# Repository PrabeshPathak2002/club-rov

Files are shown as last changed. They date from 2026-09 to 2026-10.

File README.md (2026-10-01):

# Club ROV — learning and underwater sensor testing

Project repository: [PrabeshPathak2002/club-rov](https://github.com/PrabeshPathak2002/club-rov).

A six-thruster, tethered remotely operated vehicle for club operations, testing sensors for a RoboSub AUV, training new members, and outreach. The intended operating depth is **20–50 m**, a design target that still requires physical qualification.

## Explore the ROV in 3D

<table>
<tr>
<td width="78%">
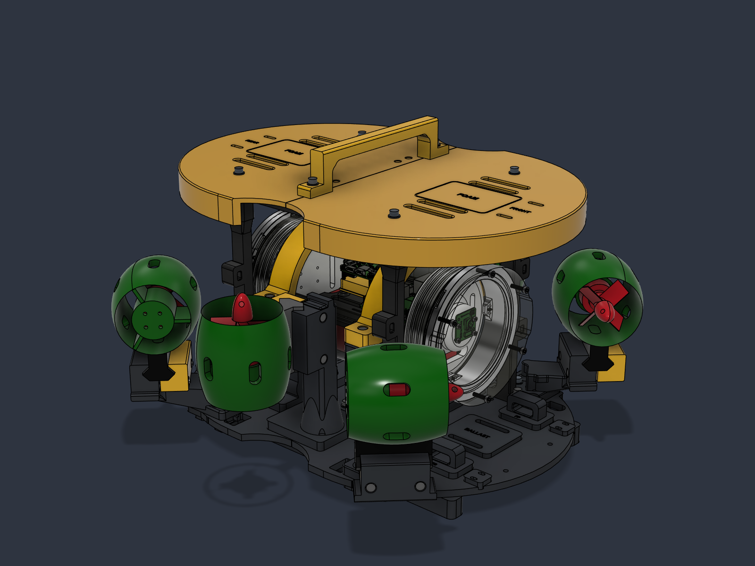
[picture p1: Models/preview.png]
Club ROV assembly in yellow and graphite — click to view in 3D

</td>
<td align="center" valign="middle">

<br><br>
Rotate, pan, and zoom the detailed model.
</td>
</tr>
</table>

[Model scope and attribution](Models/README.md). The assembly STL is for viewing, not printing.

## Purpose

- Evaluate candidate AUV sensors before integrating them into the autonomous vehicle.
- Teach CAD, additive manufacturing, electronics, embedded software, controls, and experimental testing.
- Demonstrate the club's work for promotion and recruitment, while documenting the engineering process as a portfolio project.

## Status

Latest mechanical revision: [M4 side-frame joints](Final%20Design/README.md#m4-frame-joints), standardizing the 38 custom frame/mount screws to M4. The [rear horizontal thruster pair remains corrected](Final%20Design/README.md#orientation-and-checks); the front horizontal and vertical pairs retain their orientations. The image and 3D model show this revision.

The current mechanical design and print exports are prepared. Physical assembly, electrical integration, companion firmware, and water qualification remain ahead. Existing geometry checks do not establish a depth or structural load rating.

The design uses a modular PETG frame, an existing 4-inch, 200 mm enclosure, and six APISQUEEN U01 thrusters. An ARK FPV running ArduSub is planned for vehicle control; a Waveshare ESP32-P4-WIFI6-POE-ETH will handle camera and Ethernet communications with a USB MAVLink connection to the ARK. Propulsion uses a planned 4S 4000 mAh pack, a DakeFPV four-channel ESC, and two additional ESCs. PoE and a proposed backup battery support the companion electronics. Sensors and several electrical details remain undecided.

## Start here

- [New member learning path](Documentation/NEW_MEMBERS.md)
- [System architecture and open decisions](Documentation/ARCHITECTURE.md)
- [Testing plan](Documentation/TESTING.md) and [test report template](Documentation/templates/TEST_REPORT.md)
- [Roadmap](Documentation/ROADMAP.md)
- [Contributing](CONTRIBUTING.md)
- [Attribution and publishing scope](Documentation/PUBLISHING.md)

## Local design package

GitHub contains documentation and lightweight assembly viewing models. Binary design assets and historical files below remain local pending a distribution and attribution review; their download links will not resolve in this GitHub copy.

- **[Final Design](Final%20Design/README.md)** — current Fusion assembly, STEP, printable files, BOM, assembly guide, validation and previews. Start here.
- **[Archive](Archive/Design%20History%202026-09-29/README.md)** — preserved design history, scripts, logs and earlier revisions.
- **3D models/** — original component/reference downloads, retained in place.
- **Code/** — existing firmware/software files, retained in place.
- **Documentation/** — other project documentation and the organization script.

The earlier structure/S6Hybrid development folder has moved into Archive. Existing chat links to that older location may no longer resolve; use Final Design for the current deliverables. The cleanup preserved all 1,588 original design-history files and verified their SHA-256 hashes after the move.

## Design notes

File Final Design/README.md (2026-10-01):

# Final ROV design

Current revision: M4 side-frame joints, 30 September 2026. Start with the assembly and printing guide below.

Current orientation revision: rear horizontal pair flipped back; front horizontal and vertical pairs retain their reversed orientations. The current relieved receiver pockets and print files are unchanged by this correction. See [revision details and fit-test requirements](#orientation-and-checks). Earlier validation reports are historical where superseded by the rear-pair correction reports.

- [Complete Fusion assembly](CAD/S6_Hybrid_Service_Upgrade.f3d)
- [Print-oriented Fusion parts](CAD/Service_Upgrade_Print_Parts.f3d)
- [Frame STEP export](CAD/Service_Upgrade_Frame.step) — frame component only, not the complete enclosure/thruster assembly
- [Print package](Prints/Service_Upgrade_STLs.zip) — 27 assembly parts, 10 fit coupons, guides, BOM, checks and adapter references
- [Individual STL files](Prints/Service_Upgrade_STLs/)
- [BOM spreadsheet CSV](BOM/Current_ROV_BOM.csv) and [BOM notes](BOM/Current_ROV_BOM.md)
- [Printing and assembly guide](Guides/PRINT_GUIDE.md)
- [Validation reports](Validation/) and [design previews](Previews/)
- [Future thruster adapter references](Thruster%20Interface%20References/README.md)

Current hardware: 38 M4 custom frame/mount screws, 34 nuts, 56 washers and four M4 inserts. The reused enclosure/electronics CAD also contains 30 screw solids. The BOM explains exclusions and unspecified accessories.

## M4 frame joints

The four side-frame screws are now M4x30, with four M4 heat-set inserts (6 mm maximum OD x 8.1 mm length) and 9x4.4x0.8 mm washers. The beam holes are 4.5 mm; insert pilots are 5.6 mm diameter and 10.2 mm deep. Four uprights and two beams must be printed from the new M4 files. Test all three M4 joint coupons with the actual inserts before full printing. All 38 custom screws now use M4 threads; the imported enclosure hardware remains separately specified.

The conversion passed 71 candidate intersection checks with only the four intentional insert/pilot overlaps, plus 402 sampled service checks. All 37 STLs passed watertightness, winding, scale and solid-volume checks. Thruster transforms were retained and Fusion reported no timeline issues. These checks do not establish joint strength or a lifting rating.

## Orientation and checks

The rear port and rear starboard horizontal thrusters are flipped back to their original orientation. The front horizontal and vertical pairs retain their reversed orientations, giving four vectored horizontal and two vertical units. The current relieved receiver pockets still fit; this correction does not change printed parts or fastener quantities.

The rear-pair correction passed six candidate intersection checks and all 402 sampled service-clearance checks, with no Fusion timeline warnings or errors. The other four thruster transforms were verified unchanged. These are nominal CAD checks; physical rail fit, cable routing, motor mapping, and actual thrust directions still need testing.

This is the current design release, not a physically qualified vehicle. Lifting/attachment loads, final electronics, tether, buoyancy and ballast still require the checks described in the guide. Ten test coupons are not installed parts. The six adapter references are not complete working mounts.

Earlier revisions, experiments, scripts, raw tool logs and backups are preserved at ../Archive/Design History 2026-09-29/S6Hybrid/. No original design-history files were deleted. The archive inventory and restore instructions are in that archive's parent folder. Original source models, code and other project documents remain in their original project folders.

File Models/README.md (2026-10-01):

# Interactive assembly preview

Current revision: [M4 side-frame joints](../Final%20Design/README.md#m4-frame-joints), with the [rear horizontal pair corrected](../Final%20Design/README.md#orientation-and-checks); the front horizontal and vertical pairs retain their orientations. The relieved fixed-receiver pockets are retained.

[Open the detailed STL in GitHub's 3D viewer](club-rov-preview.stl). Drag to rotate, right-drag to pan, and scroll to zoom.

The root README displays a full-color Fusion screenshot beside a View in 3D button. Both open the detailed binary STL in GitHub's interactive viewer. The STL includes the enclosure flanges and stays below GitHub's 10 MB viewer limit. STL is monochrome; the screenshot shows the design colors.

Exported from the active Future ROV Fusion assembly on 30 September 2026. Includes the enclosure, six thrusters, frame, clamps, and handle. Internal electronics, liners, and fasteners are omitted. This mesh is not a printable assembly or a manufacturing reference; use the original individual print parts for fabrication.

The assembly includes imported enclosure and APISQUEEN U01 reference geometry alongside the custom frame and mounts. No new ownership or reuse license is asserted over third-party designs. See [publishing and attribution](../Documentation/PUBLISHING.md).

[GitHub's STL documentation](https://docs.github.com/en/get-started/writing-on-github/working-with-advanced-formatting/creating-diagrams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)

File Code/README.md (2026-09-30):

# Companion firmware workspace

Firmware is not implemented yet. This folder contains local ESP-IDF setup configuration, not a runnable ROV application.

The planned target is the Waveshare ESP32-P4-WIFI6-POE-ETH. It will handle Ethernet, the camera, and USB-host MAVLink communication with the ARK FPV running ArduSub. The ARK owns thruster control.

Implementation awaits remaining software requirements and hardware decisions. See the [architecture](../Documentation/ARCHITECTURE.md) and [roadmap](../Documentation/ROADMAP.md).

When firmware is added, record the board revision, ESP-IDF version, dependencies, build/flash/monitor commands, settings, expected startup output, and bench-test procedure. Do not publish credentials or local machine paths. Initial ignore rules admit only this README from this folder; extend them deliberately when code is ready.

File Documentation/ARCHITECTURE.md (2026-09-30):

# System architecture

Status: planned electrical architecture, recorded 29 September 2026. This is an explanation of responsibilities, not a validated wiring guide.

## Control and data

The intended command path is topside operator → Ethernet tether → ESP32-P4 → USB MAVLink → ARK FPV running ArduSub → six ESC channels → thrusters. Telemetry returns in the opposite direction. Camera data is intended to reach the surface through the ESP32 and Ethernet.

The ARK owns motor control and vehicle failsafes. The ESP32 is a companion responsible for communications and camera handling. Its USB host driver and MAVLink bridge are not implemented. Camera interface, driver, stream format, and achievable latency remain to be established.

The project owner has used the ARK with ArduSub in previous submarines; this vehicle still requires integration testing. Depth, sonar, and other sensors are deliberately undecided. For each sensor, record its power, interface, calibration, timestamps, logging format, and whether the ARK or companion will own it.

## Mechanical platform

Six APISQUEEN U01 thrusters use four horizontal and two vertical mounts. The PETG frame retains the existing 4-inch, 200 mm enclosure. Printing is planned on an H2D with 100% infill as the requested starting point. Print orientation, joints, sealing, and loads still need physical validation. The 20–50 m operating depth remains a target.

## Power

- A 4S 4000 mAh battery is planned for propulsion and the ARK battery input through the ESC harness.
- DakeFPV lists the GT 6S 55A with 3–6S input and VBAT output. ARK lists a 5.5–54 V VBAT input. These ranges support the proposed feed; cable pin order is unverified.
- Two additional ESCs supply channels five and six; exact models are TBD.
- PoE powers the companion and accessories. Backup battery chemistry, capacity, charging, power-path circuitry, and switchover behavior remain TBD.
- Simultaneous ARK VBAT and USB power behavior needs verification. Backup power cannot restore a severed Ethernet link.

## Open decisions and checks

1. ESC connector wiring and reversible thrust operation; bidirectional DShot wording alone does not confirm reverse thrust.
2. USB enumeration, power interaction, MAVLink routing, and reconnect behavior.
3. Camera compatibility and video/control latency under load.
4. Power consumption, PoE budget, battery endurance, and thermal behavior.
5. Tether, penetrators, sealing, buoyancy, ballast, and depth qualification.
6. Topside software, operator controls, and explicit ArduSub link-loss behavior.

## Primary references

- [DakeFPV GT 6S 55A](https://www.dakefpv.com/pd.jsp?id=97)
- [ARK FPV pinout](https://docs.arkelectron.com/products/flight-controller/ark-fpv/pinout)
- [Waveshare ESP32-P4-WIFI6-POE-ETH](https://docs.waveshare.com/ESP32-P4-WIFI6-POE-ETH)
- [Espressif USB CDC host](https://components.espressif.com/components/espressif/usb_host_cdc_acm)

Match documentation to the actual hardware revision before preparing wiring instructions.

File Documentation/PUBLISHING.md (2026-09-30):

# Publishing and attribution

GitHub includes project, training, architecture, testing, roadmap, BOM, and printing documentation, plus a detailed assembly viewing model and one design screenshot in `Models/`. The README shows the screenshot beside a View in 3D button linking to the model. This is not a backup of the full local CAD project.

## Local-only assets

The archive holds over 5 GB of development history. Imported reference models, raw logs, machine-specific configuration, CAD, STL files, ZIP packages, and previews remain local. The full Fusion assembly is approximately 110 MB. Choose a reviewed release-asset or large-file distribution method before publishing it.

Some design-document links point to local assets and will not resolve in the initial GitHub copy. Replace them with release links once reviewed downloads are published. Preserve the archive separately.

## Attribution

The layout is inspired by the Hydrocean S6 reference provided during design. The vehicle reuses an enclosure and imported commercial-component CAD. Do not imply affiliation or equivalent performance.

Record the club name, contributors and roles, source of the enclosure and each imported model, redistribution terms, and permissions for product imagery. Credit ArduSub/ArduPilot, Espressif, ARK, Waveshare, DakeFPV, and APISQUEEN where their work or hardware is used. Links to electrical references are in [ARCHITECTURE.md](ARCHITECTURE.md).

No project-wide license has been selected. Public visibility does not grant a reuse license. A future license for original code, documentation, or custom mechanics must not claim ownership of third-party assets.

For the portfolio, explain the engineering problem, your specific contributions, tradeoffs, and measured results. Credit collaborators and tools accurately; CAD checks are not physical test results.

## Publication checklist

- [x] Confirm GitHub owner, repository name, and visibility: public, [PrabeshPathak2002/club-rov](https://github.com/PrabeshPathak2002/club-rov).
- [x] Review tracked files for credentials, local paths, and unrelated content.
- [x] Create and push the repository; record its URL in the README.
- [ ] Complete attribution and select licenses with the relevant owners.
- [ ] Publish reviewed design downloads and replace local-only links.
- [ ] Add selected project photos and measured test results.

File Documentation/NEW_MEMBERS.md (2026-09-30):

# New member learning path

Begin with an unpowered vehicle or its design files and work with a project mentor. Prior underwater robotics experience is not required.

## 1. Understand the vehicle

Read the project README and [architecture](ARCHITECTURE.md). Identify the enclosure, six thrusters, flight controller, companion, tether, and power sources. Explain how a command reaches a motor and how video returns to the surface.

Deliverable: an annotated sketch and questions for your mentor.

## 2. Practice mechanical work

Read the [print guide](../Final%20Design/Guides/PRINT_GUIDE.md) and [BOM](../Final%20Design/BOM/Current_ROV_BOM.md). Start with a fit coupon. Record material, orientation, slicer settings, and measured fit. Practice heat-set inserts on a spare coupon with supervision.

Deliverable: a fit report with dimensions and photos. Fit alone does not establish strength or pressure capability. Binary print files currently belong to the complete local design package.

## 3. Trace the electronics

Use actual board documentation to identify connector orientation, polarity, signal ground, VBAT, and regulated supplies. The architecture overview is not a pin-by-pin wiring guide. Keep propulsion disabled during initial communications work.

Deliverable: a reviewed wiring sketch with exact revisions and unresolved connections marked.

## 4. Learn the software

Read [Code/README.md](../Code/README.md). Once firmware exists, reproduce a build before changing behavior. Learn what a MAVLink heartbeat means and why video alone does not prove a healthy control link.

Deliverable: a reproducible build or documentation improvement. Until firmware is available, diagram normal operation, USB reconnection, and tether loss.

## 5. Participate in supervised testing

Follow the [testing plan](TESTING.md). Agree on acceptance criteria, abort conditions, and operator/observer/recovery responsibilities before starting. Powered propulsion and water trials require the club's designated supervisor.

Deliverable: a completed [test report](templates/TEST_REPORT.md), including unexpected results and follow-up actions.

## 6. Contribute and teach

Take a small change through a pull request using [CONTRIBUTING.md](../CONTRIBUTING.md). Explain it to another member. At demonstrations, distinguish tested capabilities from planned ones.

## Common terms

- ROV: remotely operated vehicle, controlled from the surface.
- AUV: autonomous underwater vehicle.
- ESC: electronic speed controller for a motor.
- Companion: the ESP32 communications/camera board in this project.
- MAVLink: the planned flight-controller messaging protocol.
- PoE: power over Ethernet through compatible equipment.
- BOM: bill of materials.

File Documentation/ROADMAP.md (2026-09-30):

# Roadmap

## Prepared

- [x] Define club operations, AUV sensor evaluation, training, and outreach purposes.
- [x] Prepare the mechanical design, print exports, BOM, and assembly guidance.
- [x] Select companion and flight-controller responsibilities.
- [x] Draft documentation and newcomer learning path.

## Integration preparation

- [ ] Confirm camera, additional ESCs, hardware revisions, tether, and backup power.
- [ ] Verify ESC wiring/reverse operation and simultaneous USB/VBAT behavior after parts arrive.
- [ ] Define topside controls, video requirements, and failure behavior.
- [ ] Complete electrical BOM and reviewed wiring diagram.
- [ ] Confirm repository visibility and asset attribution/distribution terms.

## Companion software

- [ ] Establish a reproducible ESP-IDF build and board identification procedure.
- [ ] Bring up Ethernet and diagnostics.
- [ ] Implement USB CDC/MAVLink routing and reconnection.
- [ ] Integrate the confirmed camera and measure latency under load.
- [ ] Add logging and supported power-status reporting.
- [ ] Document setup, configuration, troubleshooting, and bench tests.

## Qualification and club use

- [ ] Validate print fit, assembly, and mechanical loading.
- [ ] Complete bench integration and failure tests.
- [ ] Qualify sealing and shallow-water operation.
- [ ] Establish demonstrated depth and endurance.
- [ ] Add sensor evaluation procedures and datasets.
- [ ] Record a demonstration and portfolio case study with measured results.

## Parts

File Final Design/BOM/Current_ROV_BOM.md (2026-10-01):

# Current ROV bill of materials

Revision: M4 side-frame joints, 30 September 2026. This is a design BOM based on the active Future ROV document and its current print exports, not a fully validated purchasing list. Model labels do not prove ownership or final electrical compatibility. Prices are not estimated.

27 printed assembly parts; six U01 thrusters. The 10 supplied fit coupons and six STEP interface references are not installed vehicle parts. PETG spool quantity must come from the slicer, including supports, brim, coupons and waste.

Custom frame/mount hardware: 38 screws, 34 nuts, 56 washers and four inserts. Separately, 30 screw solids belong to the reused enclosure/electronics assembly. Thus 68 screw solids are accounted for across those two scopes; this does not include unitemized factory thruster hardware or future accessories.

Electrical gap: one four-channel ESC is represented for six thrusters. Two additional suitable channels or a revised ESC arrangement remain unspecified. The modeled battery is labeled 4S 4000 mAh; the reference S6 vendor battery specification was not substituted.

## Printed assembly

- **1 part** — Lower collar and foot -1. PETG; 100% infill requested. Lower_collar_and_foot_-1.stl
- **1 part** — Removable upper collar -1. PETG; 100% infill requested. Removable_upper_collar_-1.stl
- **1 part** — Lower collar and foot 1. PETG; 100% infill requested. Lower_collar_and_foot_1.stl
- **1 part** — Removable upper collar 1. PETG; 100% infill requested. Removable_upper_collar_1.stl
- **1 part** — H Rear Starboard fixed receiver and support. PETG; 100% infill requested. H_Rear_Starboard_fixed_receiver_and_support.stl
- **1 part** — H Rear Port fixed receiver and support. PETG; 100% infill requested. H_Rear_Port_fixed_receiver_and_support.stl
- **1 part** — H Front Starboard fixed receiver and support. PETG; 100% infill requested. H_Front_Starboard_fixed_receiver_and_support.stl
- **1 part** — H Front Port fixed receiver and support. PETG; 100% infill requested. H_Front_Port_fixed_receiver_and_support.stl
- **1 part** — V Starboard fixed receiver and support. PETG; 100% infill requested. V_Starboard_fixed_receiver_and_support.stl
- **1 part** — V Port fixed receiver and support. PETG; 100% infill requested. V_Port_fixed_receiver_and_support.stl
- **1 part** — H Rear Starboard removable rail jaw. PETG; 100% infill requested. H_Rear_Starboard_removable_rail_jaw.stl
- **1 part** — H Rear Port removable rail jaw. PETG; 100% infill requested. H_Rear_Port_removable_rail_jaw.stl
- **1 part** — H Front Starboard removable rail jaw. PETG; 100% infill requested. H_Front_Starboard_removable_rail_jaw.stl
- **1 part** — V Starboard removable rail jaw. PETG; 100% infill requested. V_Starboard_removable_rail_jaw.stl
- **1 part** — H Front Port removable rail jaw. PETG; 100% infill requested. H_Front_Port_removable_rail_jaw.stl
- **1 part** — V Port removable rail jaw. PETG; 100% infill requested. V_Port_removable_rail_jaw.stl
- **1 part** — Rear lower deck half - H2D. PETG; 100% infill requested. Rear_lower_deck_half_-_H2D.stl
- **1 part** — Rear upper cover half - H2D. PETG; 100% infill requested. Rear_upper_cover_half_-_H2D.stl
- **1 part** — Front lower deck half - H2D. PETG; 100% infill requested. Front_lower_deck_half_-_H2D.stl
- **1 part** — Front upper cover half - H2D. PETG; 100% infill requested. Front_upper_cover_half_-_H2D.stl
- **1 part** — One-piece service handle - two bolts. PETG; 100% infill requested. One-piece_service_handle_-_two_bolts.stl
- **1 part** — Starboard rear upright - M4 insert. PETG; 100% infill requested. Starboard_rear_upright_-_M4_insert.stl
- **1 part** — Starboard front upright - M4 insert. PETG; 100% infill requested. Starboard_front_upright_-_M4_insert.stl
- **1 part** — Starboard top beam - keyed M4 joints. PETG; 100% infill requested. Starboard_top_beam_-_keyed_M4_joints.stl
- **1 part** — Port rear upright - M4 insert. PETG; 100% infill requested. Port_rear_upright_-_M4_insert.stl
- **1 part** — Port front upright - M4 insert. PETG; 100% infill requested. Port_front_upright_-_M4_insert.stl
- **1 part** — Port top beam - keyed M4 joints. PETG; 100% infill requested. Port_top_beam_-_keyed_M4_joints.stl

## Custom assembly hardware

- **16 screw** — M4 x 20 socket-head screw. Dimensions in mm; screw length excludes head. Material/grade to be selected.
- **4 screw** — M4 x 25 socket-head screw. Dimensions in mm; screw length excludes head. Material/grade to be selected.
- **2 screw** — M4 x 35 socket-head screw. Dimensions in mm; screw length excludes head. Material/grade to be selected.
- **12 screw** — M4 x 45 socket-head screw. Dimensions in mm; screw length excludes head. Material/grade to be selected.
- **4 screw** — M4 x 30 socket-head screw. Dimensions in mm; screw length excludes head. Material/grade to be selected.
- **34 nut** — M4 hex nut. Nominal 7 mm across flats x 3.2 mm thick; retained pockets are not sized for arbitrary locknuts.
- **16 washer** — M4 washer: 8 mm OD / 4.4 mm ID / 0.8 mm thick. Collar and rail-clamp washers; radii checked in active Fusion document.
- **40 washer** — M4 washer: 9 mm OD / 4.4 mm ID / 0.8 mm thick. Frame and mounting washers; radii checked in active Fusion document.
- **4 insert** — M4 heat-set insert: 6.0 mm maximum OD x 8.1 mm long. 5.6 mm nominal pilot, 10.2 mm deep. Test actual insert in coupon before full printing.

## Existing enclosure/electronics hardware

- **6 screw** — 90037A105 screw (imported CAD label). Counted separate screw solids. Thread/length and purchased item not independently verified; do not order solely from this label.
- **4 screw** — 91290A006 screw (imported CAD label). Counted separate screw solids. Thread/length and purchased item not independently verified; do not order solely from this label.
- **4 screw** — 91290A011 screw (imported CAD label). Counted separate screw solids. Thread/length and purchased item not independently verified; do not order solely from this label.
- **4 screw** — 91290A124 screw (imported CAD label). Counted separate screw solids. Thread/length and purchased item not independently verified; do not order solely from this label.
- **6 screw** — 91292A114 screw (imported CAD label). Counted separate screw solids. Thread/length and purchased item not independently verified; do not order solely from this label.
- **6 screw** — 91292A115 screw (imported CAD label). Counted separate screw solids. Thread/length and purchased item not independently verified; do not order solely from this label.

## Existing enclosure and internals

- **1 piece / assembly** — 4-inch acrylic enclosure tube, 200 mm long. Existing enclosure; measured tube OD 114.3 mm.
- **2 piece / assembly** — 4-inch O-ring flange assembly. Each imported flange assembly contains two CAD bodies. Seal quantities and kit contents require confirmation.
- **1 piece / assembly** — Front acrylic end cap. Existing Acrylic_end_cap_blank component.
- **1 piece / assembly** — Rear aluminum end cap, five M10 openings. Existing Aluminum_end_cap_5XM10 CAD label. Actual penetrator choices remain unspecified.
- **2 piece / assembly** — Internal mounting rail BR-102784-200 RevA. Reused CAD components.
- **1 piece / assembly** — Electronics tray. Existing tray; excluded from the 27 newly supplied printed frame/mount parts.

## Enclosure mounting

- **4 half** — 1 mm soft enclosure liner half. Two upper and two lower halves, one pair per collar. Not a rigid PETG print.

## Propulsion

- **4 assembly** — APISQUEEN U01 thruster with attached rail — horizontal. Includes supplied thruster/rail geometry; factory hardware is not separately itemized.
- **2 assembly** — APISQUEEN U01 thruster with attached rail — vertical. Includes supplied thruster/rail geometry; factory hardware is not separately itemized.

## Existing electronics

- **1 assembly** — Turnigy 4S 4000 mAh battery. From Battery_Turnigy_4S_4000 CAD label; actual pack and operating limits need confirmation.
- **1 assembly** — 4-in-1 55 A ESC board. From ESC_4in1_55A CAD label. Four channels represented; reversible operation and compatibility not verified.
- **1 assembly** — ARK FPV Rev 1.0 board. One board, regardless of its 887 imported CAD bodies. Role and wiring are not validated here.
- **1 assembly** — ESP32-P4-WIFI6-POE-ETH board. One board, regardless of its 821 imported CAD bodies. Power and communication implementation remains to be finalized.
- **1 assembly** — Cam V2.1 camera module. One imported camera assembly; exact electrical interface/variant to confirm.

## Unspecified / not procurement-ready

- **2 channel** — Additional thruster ESC channels. Six motors need six suitable channels; only a four-channel board is represented. Two extra channels or a replacement six-channel arrangement must be specified.
- **TBD length** — Tether cable. Diameter, length, construction and communication/power arrangement not chosen.
- **1 assembly** — Tether strain-relief assembly. Select for actual tether; use lower-frame eye through suitable soft loop/strap. Load rating unassigned.
- **TBD piece** — Cable ties / cable retention straps. Twelve printed cable-tie locations: eight upright guides and four deck tie pairs. Final routing determines quantity and size.
- **TBD set** — Buoyancy material and retaining straps. Two upper mounting areas; material, depth rating, volume and strap quantity to be selected after weight/trim assessment.
- **TBD set** — Ballast and its retention hardware. Two slotted lower mounting pads; mass and hardware depend on measured buoyancy and trim.
- **TBD assembly** — Lifting/recovery bridle or spreader arrangement. Optional future rigging for four lower-frame eyes. Routing, working load and physical tests not established.
- **TBD set** — Enclosure O-rings / seals. Confirm exact flange kit and seal sizes/quantities; not separately identifiable in the snapshot.
- **TBD set** — Cable penetrators / blanking plugs / connectors. Rear cap has five M10 openings in the CAD label; allocation and sealing hardware not finalized.
- **TBD set** — Power wiring, distribution, fuse and isolation hardware. Electrical architecture and current requirements not validated.
- **TBD set** — Topside communication/control equipment. Tether communication interface and operator controls to be specified.
- **TBD set** — Battery charger and operating spares. Support equipment; select after actual battery and electrical design are confirmed.

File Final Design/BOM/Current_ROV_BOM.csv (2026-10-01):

category | item | quantity | unit | status | notes | source
Printed assembly | Lower collar and foot -1 | 1 | part | Modeled / STL supplied | PETG; 100% infill requested. Lower_collar_and_foot_-1.stl | Current Fusion service-upgrade revision
Printed assembly | Removable upper collar -1 | 1 | part | Modeled / STL supplied | PETG; 100% infill requested. Removable_upper_collar_-1.stl | Current Fusion service-upgrade revision
Printed assembly | Lower collar and foot 1 | 1 | part | Modeled / STL supplied | PETG; 100% infill requested. Lower_collar_and_foot_1.stl | Current Fusion service-upgrade revision
Printed assembly | Removable upper collar 1 | 1 | part | Modeled / STL supplied | PETG; 100% infill requested. Removable_upper_collar_1.stl | Current Fusion service-upgrade revision
Printed assembly | H Rear Starboard fixed receiver and support | 1 | part | Modeled / STL supplied | PETG; 100% infill requested. H_Rear_Starboard_fixed_receiver_and_support.stl | Current Fusion service-upgrade revision
Printed assembly | H Rear Port fixed receiver and support | 1 | part | Modeled / STL supplied | PETG; 100% infill requested. H_Rear_Port_fixed_receiver_and_support.stl | Current Fusion service-upgrade revision
Printed assembly | H Front Starboard fixed receiver and support | 1 | part | Modeled / STL supplied | PETG; 100% infill requested. H_Front_Starboard_fixed_receiver_and_support.stl | Current Fusion service-upgrade revision
Printed assembly | H Front Port fixed receiver and support | 1 | part | Modeled / STL supplied | PETG; 100% infill requested. H_Front_Port_fixed_receiver_and_support.stl | Current Fusion service-upgrade revision
Printed assembly | V Starboard fixed receiver and support | 1 | part | Modeled / STL supplied | PETG; 100% infill requested. V_Starboard_fixed_receiver_and_support.stl | Current Fusion service-upgrade revision
Printed assembly | V Port fixed receiver and support | 1 | part | Modeled / STL supplied | PETG; 100% infill requested. V_Port_fixed_receiver_and_support.stl | Current Fusion service-upgrade revision
Printed assembly | H Rear Starboard removable rail jaw | 1 | part | Modeled / STL supplied | PETG; 100% infill requested. H_Rear_Starboard_removable_rail_jaw.stl | Current Fusion service-upgrade revision
Printed assembly | H Rear Port removable rail jaw | 1 | part | Modeled / STL supplied | PETG; 100% infill requested. H_Rear_Port_removable_rail_jaw.stl | Current Fusion service-upgrade revision
Printed assembly | H Front Starboard removable rail jaw | 1 | part | Modeled / STL supplied | PETG; 100% infill requested. H_Front_Starboard_removable_rail_jaw.stl | Current Fusion service-upgrade revision
Printed assembly | V Starboard removable rail jaw | 1 | part | Modeled / STL supplied | PETG; 100% infill requested. V_Starboard_removable_rail_jaw.stl | Current Fusion service-upgrade revision
Printed assembly | H Front Port removable rail jaw | 1 | part | Modeled / STL supplied | PETG; 100% infill requested. H_Front_Port_removable_rail_jaw.stl | Current Fusion service-upgrade revision
Printed assembly | V Port removable rail jaw | 1 | part | Modeled / STL supplied | PETG; 100% infill requested. V_Port_removable_rail_jaw.stl | Current Fusion service-upgrade revision
Printed assembly | Rear lower deck half - H2D | 1 | part | Modeled / STL supplied | PETG; 100% infill requested. Rear_lower_deck_half_-_H2D.stl | Current Fusion service-upgrade revision
Printed assembly | Rear upper cover half - H2D | 1 | part | Modeled / STL supplied | PETG; 100% infill requested. Rear_upper_cover_half_-_H2D.stl | Current Fusion service-upgrade revision
Printed assembly | Front lower deck half - H2D | 1 | part | Modeled / STL supplied | PETG; 100% infill requested. Front_lower_deck_half_-_H2D.stl | Current Fusion service-upgrade revision
Printed assembly | Front upper cover half - H2D | 1 | part | Modeled / STL supplied | PETG; 100% infill requested. Front_upper_cover_half_-_H2D.stl | Current Fusion service-upgrade revision
Printed assembly | One-piece service handle - two bolts | 1 | part | Modeled / STL supplied | PETG; 100% infill requested. One-piece_service_handle_-_two_bolts.stl | Current Fusion service-upgrade revision
Printed assembly | Starboard rear upright - M4 insert | 1 | part | Modeled / STL supplied | PETG; 100% infill requested. Starboard_rear_upright_-_M4_insert.stl | Current Fusion service-upgrade revision
Printed assembly | Starboard front upright - M4 insert | 1 | part | Modeled / STL supplied | PETG; 100% infill requested. Starboard_front_upright_-_M4_insert.stl | Current Fusion service-upgrade revision
Printed assembly | Starboard top beam - keyed M4 joints | 1 | part | Modeled / STL supplied | PETG; 100% infill requested. Starboard_top_beam_-_keyed_M4_joints.stl | Current Fusion service-upgrade revision
Printed assembly | Port rear upright - M4 insert | 1 | part | Modeled / STL supplied | PETG; 100% infill requested. Port_rear_upright_-_M4_insert.stl | Current Fusion service-upgrade revision
Printed assembly | Port front upright - M4 insert | 1 | part | Modeled / STL supplied | PETG; 100% infill requested. Port_front_upright_-_M4_insert.stl | Current Fusion service-upgrade revision
Printed assembly | Port top beam - keyed M4 joints | 1 | part | Modeled / STL supplied | PETG; 100% infill requested. Port_top_beam_-_keyed_M4_joints.stl | Current Fusion service-upgrade revision
Custom assembly hardware | M4 x 20 socket-head screw | 16 | screw | Modeled | Dimensions in mm; screw length excludes head. Material/grade to be selected. | Current Fusion service-upgrade revision
Custom assembly hardware | M4 x 25 socket-head screw | 4 | screw | Modeled | Dimensions in mm; screw length excludes head. Material/grade to be selected. | Current Fusion service-upgrade revision
Custom assembly hardware | M4 x 35 socket-head screw | 2 | screw | Modeled | Dimensions in mm; screw length excludes head. Material/grade to be selected. | Current Fusion service-upgrade revision
Custom assembly hardware | M4 x 45 socket-head screw | 12 | screw | Modeled | Dimensions in mm; screw length excludes head. Material/grade to be selected. | Current Fusion service-upgrade revision
Custom assembly hardware | M4 x 30 socket-head screw | 4 | screw | Modeled | Dimensions in mm; screw length excludes head. Material/grade to be selected. | Current Fusion service-upgrade revision
Custom assembly hardware | M4 hex nut | 34 | nut | Modeled | Nominal 7 mm across flats x 3.2 mm thick; retained pockets are not sized for arbitrary locknuts. | Current Fusion service-upgrade revision
Custom assembly hardware | M4 washer: 8 mm OD / 4.4 mm ID / 0.8 mm thick | 16 | washer | Modeled | Collar and rail-clamp washers; radii checked in active Fusion document. | Current Fusion service-upgrade revision
Custom assembly hardware | M4 washer: 9 mm OD / 4.4 mm ID / 0.8 mm thick | 40 | washer | Modeled | Frame and mounting washers; radii checked in active Fusion document. | Current Fusion service-upgrade revision
Custom assembly hardware | M4 heat-set insert: 6.0 mm maximum OD x 8.1 mm long | 4 | insert | Design basis; exact product unconfirmed | 5.6 mm nominal pilot; 10.2 mm deep. Test actual insert in coupon before full printing. | Current Fusion service-upgrade revision
Existing enclosure/electronics hardware | 90037A105 screw (imported CAD label) | 6 | screw | Modeled in reused assembly | Counted separate screw solids. Thread/length and purchased item not independently verified; do not order solely from this label. | Original enclosure snapshot in active Fusion document
Existing enclosure/electronics hardware | 91290A006 screw (imported CAD label) | 4 | screw | Modeled in reused assembly | Counted separate screw solids. Thread/length and purchased item not independently verified; do not order solely from this label. | Original enclosure snapshot in active Fusion document
Existing enclosure/electronics hardware | 91290A011 screw (imported CAD label) | 4 | screw | Modeled in reused assembly | Counted separate screw solids. Thread/length and purchased item not independently verified; do not order solely from this label. | Original enclosure snapshot in active Fusion document
Existing enclosure/electronics hardware | 91290A124 screw (imported CAD label) | 4 | screw | Modeled in reused assembly | Counted separate screw solids. Thread/length and purchased item not independently verified; do not order solely from this label. | Original enclosure snapshot in active Fusion document
Existing enclosure/electronics hardware | 91292A114 screw (imported CAD label) | 6 | screw | Modeled in reused assembly | Counted separate screw solids. Thread/length and purchased item not independently verified; do not order solely from this label. | Original enclosure snapshot in active Fusion document
Existing enclosure/electronics hardware | 91292A115 screw (imported CAD label) | 6 | screw | Modeled in reused assembly | Counted separate screw solids. Thread/length and purchased item not independently verified; do not order solely from this label. | Original enclosure snapshot in active Fusion document
Existing enclosure and internals | 4-inch acrylic enclosure tube, 200 mm long | 1 | piece / assembly | Modeled; reuse intended | Existing enclosure; measured tube OD 114.3 mm. | Current Fusion service-upgrade revision
Existing enclosure and internals | 4-inch O-ring flange assembly | 2 | piece / assembly | Modeled; reuse intended | Each imported flange assembly contains two CAD bodies. Seal quantities and kit contents require confirmation. | Current Fusion service-upgrade revision
Existing enclosure and internals | Front acrylic end cap | 1 | piece / assembly | Modeled; reuse intended | Existing Acrylic_end_cap_blank component. | Current Fusion service-upgrade revision
Existing enclosure and internals | Rear aluminum end cap, five M10 openings | 1 | piece / assembly | Modeled; reuse intended | Existing Aluminum_end_cap_5XM10 CAD label. Actual penetrator choices remain unspecified. | Current Fusion service-upgrade revision
Existing enclosure and internals | Internal mounting rail BR-102784-200 RevA | 2 | piece / assembly | Modeled; reuse intended | Reused CAD components. | Current Fusion service-upgrade revision
Existing enclosure and internals | Electronics tray | 1 | piece / assembly | Modeled; reuse intended | Existing tray; excluded from the 27 newly supplied printed frame/mount parts. | Current Fusion service-upgrade revision
Enclosure mounting | 1 mm soft enclosure liner half | 4 | half | Modeled; material to select | Two upper and two lower halves, one pair per collar. Not a rigid PETG print. | Current Fusion service-upgrade revision
Propulsion | APISQUEEN U01 thruster with attached rail — horizontal | 4 | assembly | Modeled | Includes supplied thruster/rail geometry; factory hardware is not separately itemized. | Current Fusion service-upgrade revision
Propulsion | APISQUEEN U01 thruster with attached rail — vertical | 2 | assembly | Modeled | Includes supplied thruster/rail geometry; factory hardware is not separately itemized. | Current Fusion service-upgrade revision
Existing electronics | Turnigy 4S 4000 mAh battery | 1 | assembly | Present in CAD; configuration unverified | From Battery_Turnigy_4S_4000 CAD label; actual pack and operating limits need confirmation. | Current Fusion service-upgrade revision
Existing electronics | 4-in-1 55 A ESC board | 1 | assembly | Present in CAD; configuration unverified | From ESC_4in1_55A CAD label. Four channels represented; reversible operation and compatibility not verified. | Current Fusion service-upgrade revision
Existing electronics | ARK FPV Rev 1.0 board | 1 | assembly | Present in CAD; configuration unverified | One board, regardless of its 887 imported CAD bodies. Role and wiring are not validated here. | Current Fusion service-upgrade revision
Existing electronics | ESP32-P4-WIFI6-POE-ETH board | 1 | assembly | Present in CAD; configuration unverified | One board, regardless of its 821 imported CAD bodies. Power and communication implementation remains to be finalized. | Current Fusion service-upgrade revision
Existing electronics | Cam V2.1 camera module | 1 | assembly | Present in CAD; configuration unverified | One imported camera assembly; exact electrical interface/variant to confirm. | Current Fusion service-upgrade revision
Unspecified / not procurement-ready | Additional thruster ESC channels | 2 | channel | Required or optional provision; see notes | Six motors need six suitable channels; only a four-channel board is represented. Two extra channels or a replacement six-channel arrangement must be specified. | Current Fusion service-upgrade revision
Unspecified / not procurement-ready | Tether cable | TBD | length | Required or optional provision; see notes | Diameter, length, construction and communication/power arrangement not chosen. | Current Fusion service-upgrade revision
Unspecified / not procurement-ready | Tether strain-relief assembly | 1 | assembly | Required or optional provision; see notes | Select for actual tether; use lower-frame eye through suitable soft loop/strap. Load rating unassigned. | Current Fusion service-upgrade revision
Unspecified / not procurement-ready | Cable ties / cable retention straps | TBD | piece | Required or optional provision; see notes | Twelve printed cable-tie locations: eight upright guides and four deck tie pairs. Final routing determines quantity and size. | Current Fusion service-upgrade revision
Unspecified / not procurement-ready | Buoyancy material and retaining straps | TBD | set | Required or optional provision; see notes | Two upper mounting areas; material, depth rating, volume and strap quantity to be selected after weight/trim assessment. | Current Fusion service-upgrade revision
Unspecified / not procurement-ready | Ballast and its retention hardware | TBD | set | Required or optional provision; see notes | Two slotted lower mounting pads; mass and hardware depend on measured buoyancy and trim. | Current Fusion service-upgrade revision
Unspecified / not procurement-ready | Lifting/recovery bridle or spreader arrangement | TBD | assembly | Required or optional provision; see notes | Optional future rigging for four lower-frame eyes. Routing, working load and physical tests not established. | Current Fusion service-upgrade revision
Unspecified / not procurement-ready | Enclosure O-rings / seals | TBD | set | Required or optional provision; see notes | Confirm exact flange kit and seal sizes/quantities; not separately identifiable in the snapshot. | Current Fusion service-upgrade revision
Unspecified / not procurement-ready | Cable penetrators / blanking plugs / connectors | TBD | set | Required or optional provision; see notes | Rear cap has five M10 openings in the CAD label; allocation and sealing hardware not finalized. | Current Fusion service-upgrade revision
Unspecified / not procurement-ready | Power wiring, distribution, fuse and isolation hardware | TBD | set | Required or optional provision; see notes | Electrical architecture and current requirements not validated. | Current Fusion service-upgrade revision
Unspecified / not procurement-ready | Topside communication/control equipment | TBD | set | Required or optional provision; see notes | Tether communication interface and operator controls to be specified. | Current Fusion service-upgrade revision
Unspecified / not procurement-ready | Battery charger and operating spares | TBD | set | Required or optional provision; see notes | Support equipment; select after actual battery and electrical design are confirmed. | Current Fusion service-upgrade revision

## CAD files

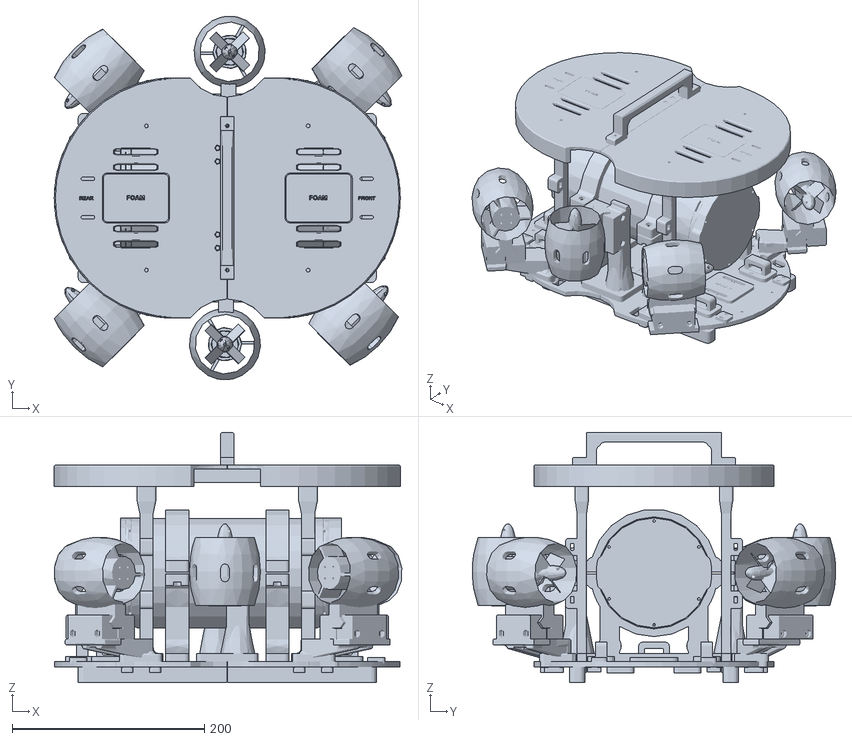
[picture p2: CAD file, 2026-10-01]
Models/club-rov-preview.stl
361.5 x 377.4 x 260.0

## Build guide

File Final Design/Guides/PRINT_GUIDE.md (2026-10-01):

# ROV service upgrade — PETG / H2D

## Current revision: M4 side-frame joints

The four side-frame joints now use M4x30 socket-head screws and 9 mm OD / 4.4 mm ID / 0.8 mm washers. Reprint the four uprights and two top beams; their new filenames contain M4. Use the three updated M4 fit coupons. The rest of the printed geometry is unchanged by this fastener conversion.

### Retained thruster orientation

The rear horizontal U01 pair is flipped back to its original orientation; the front horizontal and vertical pairs retain their reversed orientations. The relieved receiver pockets and fit coupon from the preceding revision still fit this configuration, so no additional reprint is needed for this correction. Use the current package rather than receiver STLs from before the pocket-relief revision. Mounting feet and fastener quantities are retained. Read the [orientation revision](../README.md#orientation-and-checks) and test the revised coupon before printing the full receivers.

Use S6_Hybrid_Service_Upgrade.f3d and the complete Service_Upgrade_STLs.zip together. The frame height, original enclosure, U01 thrusters, keyed mounting interfaces and both three-piece side frames are retained. The previous assembly is preserved under Archive/Design History 2026-09-29/S6Hybrid/service_upgrade/Before_service_upgrade.f3d at the project root.

## Changes to the printed parts

- Rear lower deck: dedicated centerline tether eye, two bridle attachment eyes, ballast mounting pad, two cable-tie pairs and two drain holes.
- Front lower deck: two bridle attachment eyes, ballast mounting pad, two cable-tie pairs and two drain holes.
- Four uprights: two outward-facing cable-tie guides each. Their openings are outside the original post section and away from the M4 insert seats.
- Both covers: a flush 70 x 52 mm outlined buoyancy mounting area, identification engraving and two additional 14 x 4 mm air-escape slots each. The existing cover slots accept retaining straps. The cover roof remains flat for roof-down printing.
- Physical labels identify FRONT, REAR, FOAM, BALLAST, TETHER and the FP/FS/RP/RS bridle positions. P is port, S is starboard, F is front, R is rear.

No rigid parts or screws were added. The package contains 27 assembly STLs and 10 fit coupons, 37 STL files total. Metal hardware remains 38 screws, 34 nuts, 56 washers and four heat-set inserts. Straps, ties, buoyancy material, ballast and any optional ballast fasteners are additional items and are not modeled or included in that count.

## Tether and cable routing

The rear tether eye is centered at X=-151, Y=0, Z=28 mm. Its 20 x 7 mm aperture is intended for a soft loop or strap attached to suitable tether-specific strain relief, not for clamping an unknown cable directly. The slot entrances have R0.8 edge rounds. Fit the actual strap/loop before use; the tether diameter remains unspecified.

Tether tension should transfer into the lower rear deck. Leave a slack service loop between strain relief and the enclosure connection. Never use the enclosure connector or a cable tie alone as the primary tether anchor. [Blue Robotics tether guidance](https://bluerobotics.com/store/cables-connectors/cables/fathom-rov-tether-rov-ready/) likewise calls for transferring tether pull away from the penetrator.

Four deck tie pairs have nominal 6 x 3 mm slots. Eight upright guides have 4 x 7 mm openings and R0.5 entrance rounds. Use ties no wider than 5 mm, subject to actual fit. Route branches below and inboard of the horizontal thrusters, then along the side uprights toward the rear enclosure connection. Keep service loops secured outside every propeller path. No cable diameter, minimum bend radius or flexible cable sweep has been verified; check these with actual cables and the thruster manufacturer's requirements. Remove sharp print residue without enlarging structural joints.

## Buoyancy and trim provisions

The two upper mounting areas are centered at X=+/-95, Y=0, Z=222 mm. Their outlines are 0.4 mm deep and their labels are 0.5 mm deep. Use the existing roof slots around Y=+/-32 and +/-48 mm for straps. Keep the added roof vents at X=+/-145, Y=+/-20 clear, and preserve screwdriver access at X=+/-84, Y=+/-75. Select depth-appropriate buoyancy material after the complete vehicle is weighed and its displacement assessed; printed PETG pads are not buoyancy foam.

The lower ballast pads are centered at X=+/-112, Y=0, Z=22 mm. Each has two 34 x 5.2 mm slots, centered at Y=+/-18 mm. These allow fore/aft adjustment using suitable M4 hardware or straps up to 25 mm wide, after checking actual fit and retention. Keep weights low and within the enclosure/attachment clearances. Added ballast and its fasteners are not yet sized. Adjust and test trim in water; [Blue Robotics' operating guide](https://bluerobotics.com/learn/bluerov2-operation/) describes checking buoyancy and adjusting ballast.

## Handle and bridle load-path review

The present handle transfers lifting force through its two M4 bolts into the two top beams. Upward beam loads then reach the four M4 insert joints, the four uprights, their foot bolts, and the lower decks. The locating keys resist lateral motion; they do not independently retain the beam against upward separation. Insert pullout and PETG creep are therefore relevant to lifting. This review does not establish a working load limit.

Four lower-frame eyes at X=+/-120, Y=+/-55, Z=28 mm provide attachment provisions for a separately designed bridle or recovery system. Each has a rounded 20 x 7 mm opening through a 12 mm thick eye, with R0.8 entrance rounds. A properly arranged system could take loads directly into the lower decks, but a complete rigging route, strap selection and rating have NOT been established. These are not certified lifting eyes. A straight converging bridle can contact the enclosure or covers; do not assume that fitting four straps creates an acceptable lifting arrangement. Select and check the full rigging geometry with the actual vehicle and, if needed, a spreader arrangement before using the points.

Once the finished mass is known, test representative PETG/insert joints and the complete handle and proposed recovery arrangement separately. Use a restrained bench setup, measure load and displacement, and inspect for insert movement, cracking, layer separation, screw loosening and time-dependent deformation. The small fit coupons do not substitute for complete-frame load tests. No physical testing or new FEA was performed in this revision, and no load rating is assigned.

## Future thruster adapters

The Thruster Interface References folder contains six STEP base references and a dimension/placement manifest. Existing mounts already use two keyed feet and one M4 retainer per station. Retain these interfaces and design a new upper support around the actual future thruster CAD. The horizontal patterns are handed; the vertical mounts are a separate interface family. These reference solids are not complete mounts and should not be printed as operational adapters.

Keep the 14 mm installation slide, bearing shoulders, locking bore and tool access. Check actual duct and propeller clearances, inlet/outlet flow space, cables, cover openings, thrust loads and print orientation. Current frame height is preserved, but no unspecified larger thruster is guaranteed to fit.

## Printing and assembly

PETG with 100% infill, as requested. Use the per-part orientation and notes in service_print_exports.json. All parts are checked against the conservative H2D 300 x 320 x 325 mm envelope, with 3 mm brim allowance. The revised lower decks are supplied skids/underside down, with their new eyes upright; removable support is needed beneath unsupported deck areas and channels, and may be needed at the eye apertures. This replaces the old top-face-down orientation. Inspect the slicer preview and support raised guide features where required. Flush cover markings preserve the original broad roof-down printing surface. Infill percentage does not remove layer-direction weakness.

Print TEST FIRST strap eye and TEST FIRST cable guide with the actual intended settings, and check strap/tie passage, surface finish and retention. Also retain the existing rail, T-key, enclosure-liner and M4-joint coupon checks. The eye coupon is cropped from the frame; it is for fit only and does not reproduce full-frame loading.

M4 insert design basis: 6.0 mm maximum OD x 8.1 mm length, in nominal 5.6 mm pilots 10.2 mm deep. This matches the envelope of [ruthex RX-M4x8.1](https://www.ruthex.de/products/ruthex-gewindeeinsatz-m4-50-stuck-rx-m4x8-1-messing-gewindebuchsen); confirm the actual product and coupon fit before printing the full frame. Install inserts before fitting the keyed beams. Nominal modeled thread overlap is 7.0 mm, with 3.0 mm screw-tip clearance above the pocket bottom. Insert envelopes retain 4.0 mm to the closest outer boss side. The four M4x30 screws also pass through the covers; the 4 mm cover or coupon spacer is required to reproduce their grip length. All existing foot, collar, cross-clamp, handle and deck bolts remain required.

For servicing, first release ties and connectors as needed and free the strain-relieved service loop. The rigid-model end-cap corridors are not a substitute for disconnecting wiring. Remove the covers for broad access. Do not force an enclosure tray or attached electronics through the cap corridor without checking its complete envelope.

## Geometry checks and remaining limits

The assembly is checked for unintended interference, single-solid integrity, timeline health and hardware count. M4_Frame_Joints_service_verification.json records nominal 126 mm diameter, 120 mm axial end-cap corridors; 8 mm driver approach corridors above the four M4 cover screws; and sampled removal motions of all six mounted U01 modules against the revised frame parts. Sampling is a clearance screen, not a continuous-motion proof.

The intentional overlaps between heat-set insert envelopes and their pilot holes are retained. Drain and vent openings are kept away from the insert bosses, keyed mounting feet and primary joint seats. Verify actual drainage and air release during a water test, particularly once foam, straps and cables are fitted.

All exported STLs are checked for watertightness, winding, millimetre scale and agreement with native solid volume. See M4_Frame_Joints_verification.json, service_stl_verification.json and M4_Frame_Joints_service_verification.json for the measured results. Strength, wet-service durability, PETG creep, tether retention, complete rigging and future thruster compatibility remain unqualified.

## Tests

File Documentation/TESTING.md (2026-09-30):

# Validation plan

This is a proposed sequence, not a record of completed physical tests. Existing mechanical checks concern CAD geometry and meshes; they do not establish depth, lifting capacity, printed-part strength, or endurance.

Before each test, create a [report](templates/TEST_REPORT.md) stating measurable acceptance criteria, configuration, supervision, and abort conditions. Leave a test pending when necessary limits or instruments are unavailable.

1. **Unpowered inspection:** identify revisions, match connector pins, inspect prints/seals, and review wiring. Resolve discrepancies before power-up.
2. **Electronics bench:** with propulsion disabled, establish power rails, USB, Ethernet, telemetry, and camera behavior. Record voltage, current, versions, and reconnection observations.
3. **Failure behavior:** test Ethernet, USB, and PoE loss in a controlled setup. Verify ARK behavior and backup switchover independently. Companion traffic must not mask the loss of the operator connection.
4. **Propulsion:** verify channel mapping, neutral, direction, and reverse operation in a supervised arrangement following thruster operating instructions. Record actual vehicle positions rather than assuming connector numbers match them.
5. **Enclosure qualification:** establish a suitable leak/pressure procedure with the responsible supervisor before installing valuable electronics or attempting the target depth. Record conditions, duration, equipment, and criteria.
6. **Shallow water:** assess trim, buoyancy, controllability, communications, recovery, and post-test enclosure condition.
7. **Progressive depth and endurance:** expand conditions only through reviewed tests supported by component ratings and earlier results. Publish demonstrated conditions, not just the design target.
8. **Sensors and demonstrations:** qualify calibration, timestamps, logging, and effects on control/video. Establish repeatable preflight and recovery procedures before public events.

Retain concise reports, relevant measurements, credential-free configuration snapshots, and selected photos. Record failed or aborted tests. Link large logs and videos from a deliberate data archive rather than adding them casually to source history.

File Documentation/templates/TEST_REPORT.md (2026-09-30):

# Test report: <title>

- Date and report ID:
- Author and supervisor:
- Purpose:
- Status: planned / passed / failed / aborted
- Hardware and assembly revisions:
- Firmware versions and commit:
- Environment and equipment:
- Acceptance criteria agreed before testing:
- Abort conditions and recovery arrangements:

## Procedure

Record reproducible steps and settings.

## Observations

Record measurements, units, timestamps, and evidence links. Separate observations from explanations.

## Result and limitations

Compare results against each criterion. State what the test establishes and what remains unknown.

## Follow-up

Record changes, owners, and tests to repeat.

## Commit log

2026-09-30 Document club ROV architecture, training, and validation plan
    [Current_ROV_BOM.csv]
2026-09-30 Add interactive ROV assembly preview to README
    [club-rov-preview.stl]
2026-09-30 Retain extra detail on covers and thrusters in inline preview
2026-09-30 Use decimal STL normals for viewer compatibility
2026-09-30 Replace inline mesh with color image and View in 3D button
2026-09-30 Reverse all six thrusters and update receiver fit and assembly previews
    [club-rov-preview.stl]
2026-09-30 Correct rear horizontal thruster orientation and update assembly previews
    [club-rov-preview.stl]
2026-10-01 Standardize printed side-frame joints to M4 hardware
    [Current_ROV_BOM.csv, club-rov-preview.stl]
2026-10-24 Add Unity pool simulator with six-thruster dynamics
2026-10-24 Record live Fusion geometry and PETG Basic print specification
2026-10-24 Integrate measured thruster geometry and validate pilot controls
2026-10-24 Add Pi-camera-style FPV feed with clean chase view
2026-10-24 Integrate ArduSub SITL with Unity ROV physics and local ground station
2026-10-24 Add scored ROV scenarios, disturbances and underwater camera training
2026-10-24 Apply official RoboSub 2026 task artwork and aligned board cutouts
2026-10-24 Add collapsible telemetry panels and top-down camera view
2026-10-24 Refresh simulator guide for current maps HUD and control modes
2026-10-24 Replace outdated simulator README image with current OSD capture
2026-10-25 Consolidate current ROV BOM and label historical CAD inventory
